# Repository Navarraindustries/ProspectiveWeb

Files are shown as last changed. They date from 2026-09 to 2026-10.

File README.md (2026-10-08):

# PROSPECTIVE Web

> Computer-assisted planning for cerebral aneurysm surgery, in the browser.
> FastAPI backend (VTK · SimpleITK · pydicom) + React/TypeScript frontend with
> real-time 3D and MPR viewers — the web port of the PROSPECTIVE desktop app.

---

## Table of Contents

- [Overview](#overview)
- [Status](#status)
- [Tech Stack](#tech-stack)
- [Project Structure](#project-structure)
- [Prerequisites](#prerequisites)
- [Installation](#installation)
- [Running the App](#running-the-app)
- [Environment Variables](#environment-variables)
- [Data Model](#data-model)
- [Session Lifecycle](#session-lifecycle)
- [Undoing Work](#undoing-work)
- [Choosing a Clip](#choosing-a-clip)
- [Navigation & Unsaved Work](#navigation--unsaved-work)
- [API Reference](#api-reference)
- [Running Tests](#running-tests)
- [Development Scripts](#development-scripts)
- [Relationship to the Desktop App](#relationship-to-the-desktop-app)
- [Known Limitations](#known-limitations)
- [Privacy & Security Notes](#privacy--security-notes)
- [License](#license)

---

## Overview

PROSPECTIVE Web is a clinical decision-support system for neurosurgical planning
of cerebral aneurysms. A clinician uploads a DICOM study and walks a seven-step
pipeline, with every step rendered live in 3D:

```
1 DICOM upload  →  2 Segmentation  →  3 Detection  →  4 Morphometry
      →  5 Treatment decision  →  6 Devices  →  7 Report
```

All medical image processing runs on the server (VTK + SimpleITK); the browser
renders meshes with vtk.js and 2D slices as server-rendered PNGs.

Every step of that pipeline is **reversible**: the mesh carries an undo/redo
history, the preprocessing can be rolled back to the original DICOM, and the
detection, morphometry, centreline, treatment decision and placed devices can each
be cleared without restarting the study. Nothing derived from a result outlives
the result itself, so the 3D scene, the measurements and the PDF can never
disagree with one another.

Beyond the pipeline the platform covers the surrounding clinical workflow:
patient registry, clinical cases, a durable archive of imaging studies with a
searchable preview gallery, resumable planning sessions, user signup with admin
approval, and a tamper-evident audit chain.

---

## Status

| | |
|---|---|
| Backend tests | **1594 passing** (`pytest`, 105 files) |
| Frontend tests | **459 passing** (`vitest`, 65 files) · `tsc -b` clean · production build clean |
| REST endpoints | **149** operations (28 routers), all authenticated except login/signup/logout; `/docs` and `/openapi.json` also require a session |
| Feature parity with desktop | **Complete** |

---

## Tech Stack

| Layer | Technology |
|---|---|
| API framework | FastAPI 0.110+ with Uvicorn |
| Medical imaging | SimpleITK 2.3, VTK 9.3, pydicom 2.4, scipy 1.12, Pillow 10 |
| Mesh processing | VTK (Marching Cubes, smoothing, decimation, STL export) |
| Auth | python-jose (JWT HS256), passlib + bcrypt 4.x |
| Database | SQLAlchemy 2.0 + SQLite (WAL mode) |
| Report generation | reportlab 4.x (PDF), pydicom (DICOM SR) |
| Study archive | pluggable local filesystem or AWS S3 (boto3, optional) |
| Frontend | React 19 + TypeScript 5.8 + Vite 7 |
| 3D / 2D viewers | @kitware/vtk.js 36 (meshes, MPR, oblique reslice and MIP rendered client-side from a chunked int16 copy of the volume) |
| Routing | react-router-dom 7 |
| Python | 3.11+ (developed on 3.13) · Node 20+ |

---

## Project Structure

```
ProspectiveWeb/
├── Makefile                # Dev shortcuts
├── start-all.bat           # Windows: launches backend + frontend in two windows
│
├── backend/
│   ├── main.py             # FastAPI app: lifespan, CORS, static mounts, guarded routers
│   ├── requirements.txt
│   ├── models/    (20)     # Pydantic request/response schemas
│   ├── routers/   (23)     # Route handlers, one file per domain
│   ├── services/  (40)     # Qt-free business logic, shared with the desktop app
│   ├── test_*.py  (39)     # pytest suites
│   ├── data/               # PUBLIC static mount — sessions, meshes, reports
│   ├── clip_library/       # PRIVATE: institutional clips + templates (gitignored)
│   ├── study_files/        # PRIVATE archive: DICOM of archived studies (gitignored)
│   ├── user_files/         # PRIVATE: signup photos and CVs (gitignored)
│   └── secrets/            # PRIVATE: JWT signing key (gitignored)
│
└── frontend/
    ├── src/
    │   ├── pages/          # Landing · Login · Signup · Patients · NuevoCaso
    │   │                   # Studies · Workspace · PendingRequests · UsersAdmin · AuditTrail
    │   ├── components/     # Design-system primitives + one panel per pipeline step
    │   ├── vtk/            # MeshView · VolumeView · MprView · ObliqueMprView · Viewer
    │   ├── store/          # planning · auth · nav · theme contexts
    │   ├── *.test.*  (8)   # vitest + Testing Library suites
    │   └── styles/tokens/  # Design tokens (light/dark via [data-theme])
    └── public/media/       # Intro / loading / landing videos
```

Key backend services (all ported from the desktop `prospective/processing`):

| Service | Purpose |
|---|---|
| `dicom_loader.py` | SimpleITK series loading, multi-series scan, Enhanced XA multiframe |
| `thresholds.py` | Auto HU/intensity band per modality (CT · MR · XA · DSA strategies) |
| `preprocess.py` | HU clipping, isotropic resampling, Gaussian smoothing, bone subtraction |
| `segmentation.py` | Marching Cubes → component filter → smoothing → decimation |
| `mesh_crop.py` | Box/sphere ROI clipping · plane cut (no centre to pick) · region eraser |
| `mesh_components.py` | Connected-piece analysis: keep only the vascular tree, or delete one piece by click. Refuses on CTA, where the largest piece is the whole head |
| `aneurysm_detector.py` | Curvature + shape-gate candidate detection |
| `aneurysm_consensus.py` | Three independent channels — curvature, local calibre, calibre vs the neighbouring vessel — merged into one shortlist |
| `morphometrics.py` | Neck / dome / AR / DNR / BF / UI / EI / NSI with reliability guards |
| `sac_isolation.py` | Semi-automatic watertight sac isolation from two clicks |
| `parent_artery.py` | Parent-vessel diameter → size ratio |
| `centerline.py` / `cross_section.py` | Medial-axis extraction · diameter profile · stenosis |
| `perforator_risk.py` | Vertex-valence anomaly → perforator candidates |
| `treatment.py` | Heuristic CLIP vs ENDOVASCULAR scoring, every weight carrying its provenance |
| `jsdb.py` | Japan Stroke Data Bank: fitted poor-outcome risk for EACH route. Ruptured only; describes, never votes |
| `clips.py` / `coils.py` / `devices.py` | Device catalogues, recommendations, real VTK collision |
| `clip_selection.py` | Criteria-based clip choice per case + manufacturing spec |
| `clip_fit.py` | Poses candidates on the measured neck and checks them against the mesh |
| `clip_library.py` | Global store of the institution's clips and manufacturing templates |
| `navarro.py` | The NAVARRO™ made-to-order family: jaw sizing, jaw-only resizing |
| `clip_animation.py` | Splits a clip into body + blades and derives its hinge, for rehearsal |
| `clip_manufacture.py` | The clip to have made: family, commercial fallback, or neither |
| `clip_dossier.py` | The two order PDFs — internal record and workshop copy |
| `clip_orders.py` | The order register and the workshop directory — global, persistent, frozen |
| `stent_deployment.py` | Centerline-guided braided stent along real vessel curvature |
| `phases.py` | PHASES 5-year rupture risk (Greving 2014) |
| `mesh_prep.py` | 3D-print preparation + printer-bed presets |
| `scene_render.py` | Offscreen VTK renders of the scene from named, fixed viewpoints |
| `report_generator.py` / `dicom_sr.py` / `mesh_exporter.py` | PDF · DICOM SR · STL |
| `audit.py` | SkullChain SHA-256 tamper-evident event chain |
| `storage.py` / `study_archive.py` | Durable study archive (local or S3) + previews |
| `mesh_backup.py` | Undo/redo stacks for the working mesh, with a labelled manifest |
| `device_state.py` | Which devices a session has placed; clearing one family |
| `sessions.py` | Session dirs, TTL purge, durable snapshot / rehydrate |

### Segmentación tubular

El método tubular (`services/vascular_mask.py` + `mask_to_surface` en `services/segmentation.py`) rellena el núcleo de la banda de umbral y mide su tubularidad con Frangi por lonchas. Siembra en los troncos (percentil 90, ≥ 50 mm³) y crece por histéresis solo lo conectado a ellos. Después recupera hasta 3 mm de pared y sacos, vetando lo que es lámina (hueso). La superficie sale de marching cubes sobre la máscara suavizada, con un vóxel vacío alrededor que tapa los vasos que salen por el borde del volumen. Cada segmentación informa de las aristas de borde, las piezas, las semillas y los mm³ recuperados y vetados. `backend/scripts/validate_case3.py` mide todo eso sobre Case 3 (384³, 0,32 mm, umbral 1470), y en este equipo (16 núcleos) da estas cifras. La decimación (45 %) usa `vtkDecimatePro` con la topología preservada: la cuadrática abría 25 aristas de borde en una malla que llegaba cerrada.

| Case 3 | Cifra |
|---|---|
| Aristas de borde | 0 (2 no-variedad, aceptadas) |
| Piezas | 6 (1 con «solo el árbol»); ninguna con aspecto de hueso |
| Semillas | 8 |
| Relación de aspecto mediana | 1,43 |
| Lesión conservada (M0 a ≤ 3 mm) | 96,6 % |
| Vértices | 107 176 |
| Tiempo máscara + superficie | 9,0 s (34,1 s con los dos pases de Frangi) |

La variable de entorno `PROSPECTIVE_MEM_BUDGET_MB` fija el presupuesto de memoria por encima del cual el método tubular se fuerza a media resolución y lo dice. Si no está definida, el presupuesto es el 70 % de la RAM disponible que detecta el sistema (`/proc/meminfo` en Linux, `GlobalMemoryStatusEx` en Windows), y 1400 MB si no puede leerla.

La detección busca la curvatura sobre una copia de 80 000 vértices cuando la malla es mayor, y calibre y cociente sobre una de 40 000. Las regiones de curvatura que tocan una cara de la caja de la malla (las tapas de los vasos cortados por el borde del volumen) van al final de la lista. En Case 3 la lesión confirmada sale 2.ª, con «solo el árbol» y con la malla completa, y la detección tarda unos 10 s. Eso es **a resolución nativa**. A media resolución (10 594 vértices, «solo el árbol») la misma lesión sale 5.ª, el último puesto de la lista, y solo por el cociente: el objetivo «lesión ≤ 3» no se cumple ahí.

#### Despliegue

- **Memoria y resolución.** Case 3 (56,6 M vóxeles) necesita unos 2,1 GiB para el método tubular a resolución nativa. En una instancia de 2 GB el presupuesto automático (70 % de la RAM disponible) no llega, así que los estudios de ese tamaño se segmentan siempre a media resolución: la tarjeta lo dice («1/2 · Submuestreada») y la lesión de Case 3 cae al 5.º puesto. Recomendado: una instancia de 4 GB, que pasa justo, o fijar `PROSPECTIVE_MEM_BUDGET_MB` a lo que la máquina aguante de verdad.
- **Tiempo.** A media resolución, máscara más superficie de Case 3 tardan unos 27 s en un solo núcleo del equipo de desarrollo, casi todo en los dos pases de Frangi. En una vCPU compartida hay que contar con 40–80 s.
- **Proxy inverso.** La interfaz lanza la segmentación con `POST /api/segment?background=true`, que responde 202 al instante, y recoge el resultado en `GET /api/segment/result/{sid}` (409 mientras sigue en curso), así que ninguna petición dura minutos y el límite típico de 30 s del proxy basta. Sin `background` el endpoint sigue siendo síncrono, para scripts. El progreso va por `/ws/progress/…`, así que el proxy también tiene que reenviar `/ws/` con las cabeceras de actualización:

  ```nginx
  location /ws/ {
      proxy_pass http://127.0.0.1:8000;
      proxy_http_version 1.1;
      proxy_set_header Upgrade $http_upgrade;
      proxy_set_header Connection "upgrade";
      proxy_read_timeout 180s;
  }
  ```

  Sin eso el panel cae al sondeo por GET cada medio segundo, que funciona igual pero con más peticiones.
- **Un solo proceso.** Arranca uvicorn con un único worker (sin `--workers N`). El progreso de cada trabajo y el semáforo que deja correr una sola segmentación tubular a la vez viven en la memoria del proceso: con varios workers, el progreso se consultaría en un proceso que no es el que segmenta, y dos segmentaciones tubulares podrían correr a la vez y agotar la memoria. Está defendido: al arrancar, cada proceso toma un cerrojo exclusivo del sistema sobre `backend/data/.proceso.lock`, y un segundo proceso sobre los mismos datos (otro worker, o un uvicorn antiguo que siguiera vivo) no arranca y dice por qué. `PROSPECTIVE_ALLOW_MULTI_PROCESS=1` lo desactiva; solo lo usan los tests.

---

## Prerequisites

- **Python 3.11+** and **Node.js 20+**
- Windows / macOS / Linux (VTK and SimpleITK are cross-platform)

---

## Installation

```bash
git clone https://github.com/JEsteban1999/ProspectiveWeb.git
cd ProspectiveWeb

# Backend
cd backend
python -m venv .venv
.venv\Scripts\pip install -r requirements.txt      # Windows
# .venv/bin/pip install -r requirements.txt        # macOS / Linux

# Frontend
cd ../frontend
npm install
```

Or, on Windows, with the Makefile from the repo root:

```bash
make install:backend
make install:frontend
```

---

## Running the App

Double-click **`start-all.bat`** (Windows) to launch both servers, or run them
separately:

```bash
# Backend — http://127.0.0.1:8000
cd backend && .venv\Scripts\uvicorn main:app --reload --host 127.0.0.1 --port 8000

# Frontend — http://localhost:5173
cd frontend && npm run dev
```

| URL | Description |
|---|---|
| `http://localhost:5173/` | Public landing page |
| `http://localhost:5173/app` | The application (login → patients → workspace) |
| `http://127.0.0.1:8000/docs` | Swagger UI |
| `http://127.0.0.1:8000/redoc` | ReDoc |
| `http://127.0.0.1:8000/health` | Health check |

Default account seeded on first run: **`admin` / `admin123`**. Change it from the
user menu ("Cambiar contraseña") before using the app with real data — an admin
can also reset another user's password from the Usuarios page.

> **Note on `--reload`**: uvicorn's reloader does not reliably pick up *new*
> modules, and a stale process on :8000 will silently serve old code. Restart the
> backend for real when verifying a change end to end.

### With Docker

```bash
docker compose up --build -d      # → http://localhost:8080
```

Two containers: the API (`backend/Dockerfile`, one uvicorn process — progress
and background results live in memory) and nginx (`frontend/Dockerfile`) with
the built app, which also forwards `/api`, `/data` and `/ws`. Browser and API
share one origin, so the session cookie stays `SameSite` and no CORS is needed.
The database, the study archive, user files, the JWT key and the clip folders
live in named volumes; none of them is copied into the image
(`backend/.dockerignore`). `PROSPECTIVE_PORT` changes the port. Before real
patient data: put HTTPS in front and set `COOKIE_SECURE=1`. CI builds both
images and checks they answer.

---

## Environment Variables

The server runs out of the box with sensible defaults.

| Variable | Default | Description |
|---|---|---|
| `PROSPECTIVE_DB_URL` | `sqlite:///backend/data/prospective.db` | SQLAlchemy connection string |
| `JWT_SECRET` | auto-generated into `backend/secrets/jwt_secret.txt` | HS256 signing key |
| `SESSION_TTL_HOURS` | `24` | Age at which an idle working session is purged |
| `STUDY_FILES_ROOT` | `backend/study_files` | Root of the durable study archive |
| `STORAGE_BACKEND` | `local` | `local` (filesystem) or `s3` |
| `STORAGE_S3_BUCKET` | — | Required when `STORAGE_BACKEND=s3`; bucket must be private |
| `STORAGE_S3_PREFIX` | — | Optional key prefix inside the bucket |
| `COOKIE_SECURE` | off | Mark the auth cookie `Secure` (set it when serving over HTTPS) |
| `PROSPECTIVE_ALLOW_DEFAULT_ADMIN_PASSWORD` | off | `1` skips the forced change of `admin123` (tests, local dev only) |
| `CORS_ORIGINS` | Vite dev server | Comma-separated origins allowed to call the API with credentials. `*` is refused |
| `PROSPECTIVE_PLAN_VIEWS` | probed | `0` / `1` forces the report's server-rendered plan views off / on. Unset, a child process probes once whether offscreen OpenGL works: on a machine without it VTK does not raise, it kills the process |
| `BACKEND_URL` | `http://127.0.0.1:8000` | Where the Vite dev server proxies `/api`, `/data`, `/static` |

Token lifetime is currently a constant (`ACCESS_TOKEN_EXPIRE_MIN`, 24 h) in
`services/auth_service.py`, not an environment variable.

For production, always set `JWT_SECRET` from the deployment environment and never
commit it.

---

## Data Model

The clinical hierarchy is deliberately four levels deep, so one episode of care
can carry several acquisitions without duplicating records:

```
Patient  ──<  Study (clinical case)  ──<  ImagingStudy (one acquisition)
                      │                            │
                      └──────<  PlanningSession  >─┘
```

- **Patient** — demographics, history, institution.
- **Study** — the *clinical case*: diagnosis, aneurysm type, region, laterality,
  proposed treatment. Created via "Nuevo caso" against an existing patient.
- **ImagingStudy** — one archived acquisition (CT, angiography, follow-up) with
  its DICOM in durable storage plus a rendered preview. A case may hold several.
- **PlanningSession** — a saved run of the pipeline, linked to both the case and
  the acquisition it analysed, resumable from the step it was saved at.

The **Studies gallery** (the "Estudios" tab, and inside each patient sheet) lists
archived imaging studies as preview cards. The search runs **on the server**, so
it covers the whole archive — filtering only the page that happened to be loaded
made an older patient come back empty with nothing to explain why.

Each card shows the step its planning reached and offers two actions:
**«Reanudar»** restores the saved session at that step, and **«De cero»** starts a
fresh session at step 1 and says so. A card only offers to resume when the
snapshot is really on disk: sessions saved before durable saving existed, or
purged since, would otherwise fail on restore.

---

## Session Lifecycle

Every pipeline interaction is scoped to a **session** — a UUID directory:

```
backend/data/sessions/{uuid}/
├── .created_at          # ISO timestamp used for TTL cleanup
├── state.txt            # Key-value store (dicom.*, seg.*, morpho.*, treatment.*)
├── dicom/               # Uploaded DICOM files
├── meshes/              # Meshes (.vtp) + cached volume (_volume.npy)
│   ├── _undo/           # Mesh edit history + index.json manifest
│   └── _redo/           # States stepped back past, replayable
├── reports/             # Generated PDFs
└── exports/             # Exported STL files
```

Sessions are working scratch and are purged after `SESSION_TTL_HOURS`. Two
mechanisms make work survive that sweep:

- **Archiving a study** copies its DICOM into `study_files/` (or S3) and creates
  an `ImagingStudy`. This is what puts it in the gallery.
- **Saving progress** snapshots the session directory into
  `data/session_saves/{uuid}`. The DICOM is hard-linked rather than copied
  (studies are ~1 GB and copying them filled the disk); meshes and the volume
  cache are copied, because re-running a step rewrites them in place and a
  snapshot must stay a point-in-time image. The mesh undo/redo stacks are pruned
  out of the snapshot — they are a working convenience, and carrying every
  intermediate state multiplied the size of each save.

A restored session starts its own clock. `_clone_tree` copies every file in the
snapshot, `.created_at` included, so a session restored from a week-old save came
back already past the TTL and the next purge sweep deleted it mid-session, with
no message — any session older than `SESSION_TTL_HOURS` was effectively
unresumable. The live session is stamped with the time it was actually created.

What survives a save → restore, verified end to end: the segmentation and every
mesh edit, the detection, the morphometry *including the fitted neck plane and
the points marked around the rim*, the centreline, the treatment decision, the
placed devices (and so the report), and any made-to-order clip built for the
case. The marks matter as much as the measurement: the plane can be rebuilt from
its origin and normal, but a resumed session used to show that plane with
nothing behind it, and refining it meant marking the rim again from scratch.

Typical flow:

```
POST /api/upload                       → session_id + detected series
GET  /api/segment/suggested-band/{id}  → auto HU band for this modality
POST /api/segment                      → vessel_tree.vtp
POST /api/detect/{id}                  → aneurysm candidates
GET  /api/morphometry/{id}             → neck/dome measurements
POST /api/treatment-decision           → CLIP vs ENDO recommendation
POST /api/report                       → PDF assembled from session state
POST /api/studies/cases/{case}/archive → DICOM into durable storage
POST /api/sessions/save                → resumable snapshot + DB link
```

Session files are served statically under `/data/sessions/` so vtk.js can fetch
mesh URLs directly — behind a middleware that requires the same token as the API,
since those directories also hold the uploaded DICOM.

---

## Undoing Work

A planning session is exploratory: thresholds get retuned, a crop takes a vessel
with it, a case is evaluated with the wrong location. Every step therefore
has a way back that does not cost a re-upload or a re-segmentation.

| What | How to undo it | Cost |
|---|---|---|
| ROI crop · region eraser · re-segmentation | «Deshacer» — `POST /api/mesh-restore/{sid}` `scope=undo` | file copy |
| Every interactive mesh edit at once | «Restaurar malla original» — `scope=original` | file copy |
| An undo taken one step too far | «Rehacer» — `scope=redo` | file copy |
| HU clipping · resampling · smoothing · bone subtraction | «Revertir» — `DELETE /api/preprocess/{sid}` | rebuild from the session's DICOM |
| Candidates + morphometry + the neck plane | «Limpiar detección» — `DELETE /api/detect/{sid}` | instant |
| Neck or dome marker placed on the wrong spot | Clear that one marker in the morphometry panel | instant |
| The medial axis and any stent deployed along it | `DELETE /api/centerline/{sid}` | instant |
| The recommendation, its clinical context and PHASES | `DELETE /api/treatment-decision/{sid}` | instant |
| A placed clip, coil packing or stent | `DELETE /api/devices/{sid}?kind=…` | instant |
| A wrongly imported custom clip | `DELETE /api/clips/custom/{sid}/{index}` | instant |

Two rules keep the session honest while all of this happens:

- **Nothing derived outlives its source.** Restoring a mesh clears the candidates,
  morphometry and centreline measured on the old one; clearing the detection also
  clears the treatment recommendation and the PHASES score, because both are
  computed *from* the morphometry. Leaving them behind produced a PDF that
  recommended a treatment for an aneurysm the same PDF reported as unmeasured.
- **Generated outputs are cache-busted and dated.** A PDF, a DICOM SR and an STL
  are snapshots of the mesh, the measurements and the devices at the moment they
  were written. The filename is fixed per session, so the URLs carry a version
  token and the panel says when a download no longer matches what is on screen.

The mesh history lives inside the session directory, so a session that is saved
and resumed still offers «Deshacer» — the browser has no memory of edits it did
not make, and `GET /api/mesh-restore/{sid}` is what the panel asks on mount. The
same applies to the preprocessing (`GET /api/preprocess/{sid}`), the placed
devices (`GET /api/devices/{sid}`) and the imported clips
(`GET /api/clips/custom/{sid}`).

---

## Choosing a Clip

The devices step answers a specific question: **does anything we own fit this
aneurysm, and if not, what has to be made?**

### Two stages

1. **Analytic** — every clip in the catalogue is judged against the case,
   criterion by criterion. Each verdict carries the measurement that produced it,
   because "score 92.6" is not something a surgeon can check.

   | Criterion | What it compares |
   |---|---|
   | Cobertura | Blade length against the **flattened** neck (see below) |
   | Fenestración | Window calibre against the measured parent artery |
   | Alcance | Shape against dome depth (AR) |
   | Forma / localización | Shape against the anatomical region on the case |
   | Fuerza de cierre | Spring force against neck width |

2. **Geometric** — the best candidates are built at their real dimensions,
   posed on the measured neck plane and checked against the patient's own mesh.

   Two details make this mean anything. A clip across the neck necessarily
   intersects the vessel — *the neck is vessel* — so the sac and neck region are
   cut away first and the collision test runs against what remains; a hit then
   means the blade reaches a **neighbouring** structure. And several approach
   angles are tried: reporting only the best pose made a clip that clears its
   neighbours at every angle look identical to one that clears them at exactly
   one. Both numbers are reported (`clean_rolls` of `n_rolls`).

### Four outcomes, never an empty list

| Outcome | Meaning |
|---|---|
| `stock` | At least one clip meets every criterion |
| `marginal` | Usable clips exist, but all carry a caveat — the custom alternative is offered too |
| `manufacture` | Nothing fits; the answer is a specification to have one made |
| `unmeasured` | No reliable neck, so no selection is possible — mark the neck plane first |

The old recommender returned an empty list for a 1 mm neck and for a 20 mm neck
alike. An empty list *is* the answer "nothing made fits this patient"; it just
has to be delivered as a specification rather than as silence.

### The manufacturing specification

Blade length, width, height, spring, shape, angle, target closing force, and the
window diameter taken from the measured parent artery. Width, height and spring
follow the median proportions of the real catalogue rather than being invented —
but never below the smallest part that demonstrably exists. Scaling every
dimension with the blade treats a clip as one shape at different zooms, and a
2.5 mm neck then specified a 2.8 mm spring, 44 % under the shortest real one.
The spread of spring/blade across the catalogue (0.45–1.14) already says the
relation is not proportional, and the NAVARRO™ family settles it: 42 designs from
7 to 22 mm of jaw, all on the same 14.3 mm body. A spring is sized by the force
it holds, not by the blade in front of it. When a dimension is floored the spec
says so. `POST /api/clips/manufacture/{sid}` writes the STL.

**The STL comes from the drawn designs.** It used to come from the box builder —
348 triangles with 696 boundary edges for a 10 mm clip, an open surface that no
workshop or printer can take. Anything meant to be MADE is now built from the
NAVARRO™ family, which is watertight.

**A shape the family cannot build is never substituted in silence.** Available
shapes are read off the disk, so the curved and fenestrated series become
selectable by dropping their files in. Until then a fenestrated case is offered a
commercial clip of that shape — and if no commercial clip of that shape can close
the neck either, the answer is `unavailable` rather than a near-miss presented as
an alternative.

**Two dossiers.** The internal PDF records which patient, which case and which
measurements produced the dimensions, so the order can be re-derived a year
later. The workshop PDF carries no patient data by construction — dimensions,
tolerances, material and the checks to run on the finished part. They share a
part number, which is the only thread between them.

**Both dossiers show the piece.** Three renders of the very solid that goes
into the STL — superior, anterior and oblique — so a workshop can see the shape
it is quoting. A dimension table catches an order that is dimensionally wrong; a
picture catches one that is dimensionally right and shaped wrong. They carry no
patient data: they are pictures of a clip.

**The closing force is a target, never a result.** It comes from the spring, the
alloy and the heat treatment; an STL has no material. Both dossiers demand it be
measured on the finished part before anyone calls the order done.

The spec always lists what a machinist still has to confirm — a specification
that hides its assumptions is worse than one that states them. In particular,
**no parent-artery measurement means no window diameter**: the spec says so
instead of quietly falling back to a plain clip.

### The NAVARRO™ family (made to order)

`NAVARRO™ - Variantes/` holds the institution's own designs — **66 of them,
across all four series**:

| Serie | Diseños | Se varía |
|---|---|---|
| **T1 recta** | 6 (7–22 mm de mordaza) | mordaza |
| **T2 curva** | 6 | mordaza, **solo tallas dibujadas** |
| **T3 angulada** | 36 (6 acodados × 6 mordazas) | mordaza y acodado |
| **T4 fenestrada** | 18 (6 mordazas × 3 ventanas) | mordaza y ventana (3/5/7 mm) |

The curved and fenestrated series arrived by being dropped into the folder, with
no import step and no code change to read them — which was the point of reading
the library off disk. All 66 exports are watertight solids in millimetres, on the
same frame, verified before wiring them in.

**Only this family is offered.** Clips from Sugita, Aesculap, Yasargil and Codman
are no longer proposed to a surgeon: the family now covers every shape the
selector can ask for, and a clip nobody here can obtain was a dead end — it could
not be personalised and it dragged the wrong piece into the manufacturing
dossier. That table is not deleted, because it is also the dimensional reference
the manufacturing spec derives its proportions and its floors from. Reference,
never an offer (`OFFER_COMMERCIAL_CLIPS`).

Three things about them are easy to get wrong, and each is enforced in code:

- **Use the STL, never the OBJ.** The `.obj` exports are in CENTIMETRES (measured
  ratio 9.996–10.008 against the STL across all 41 pairs) *and* unwelded — the
  7 mm clip reads as 14 334 loose triangles with 43 002 boundary edges, a
  triangle soup that cannot be collision-tested. The `.stl` are already in
  millimetres and watertight. Nothing is rescaled.
- **The name states the JAW, not the clip.** A "7mm" NAVARRO grips 7 mm on a part
  21.30 mm long (`total = jaw + 14.30 mm`, constant across the family). Measuring
  the envelope and recording it as the blade makes the selector reject, as
  "oversized ×5.3", the very clip that fits a 4 mm neck. `add_clip` therefore
  accepts a declared `blade_length_mm` that overrides the measurement.
- **The closing force is a band, not a figure.** 120–200 g by design, not yet
  characterised. It travels as a band and the force criterion is capped at
  `warn` for these clips however well the band sits — "meets the criterion" is a
  claim nobody can make yet.

**Visibility.** Stock and made-to-order answer different questions — what can be
picked up today, and what would be made for this case — so the recommendation
always shows at least the best of each. Ranking alone hid the family: a design
whose closing force is still a band is capped at `warn` on that criterion, and
with a 6 mm neck 28 of the 42 designs were viable while the best ranked 12th of
60, so every visible slot went to stock. The scores are untouched; only
visibility changed.

**Resizing.** These are manufactured per case, so the jaw is not restricted to
the six drawn sizes: `POST /api/clips/navarro/{sid}` builds any jaw length, and
the panel both suggests the one the neck asks for and lets it be set by hand.
The stretch applies to the **jaw only, along its own axis** — the body and spring
are left exactly as drawn, because a uniform scale would resize the spring too
and its closing force would no longer be the family's. That is legitimate rather
than invented: sampling the jaw taper at ten stations and normalising by length,
the profiles agree to within ~0.05 mm across the drawn sizes, so the designs are
one shape stretched. Where the jaw *starts* is read off each mesh rather than
assumed — it is 2.50 mm at 0° and 90° but 3.95 mm at 15°, because the knee takes
up room. A stretched mesh is a faithful preview for display and collision
testing, **not** the manufacturing master.

### «Fabricación», a step of its own

Ordering a piece is not planning a case. Everything in **Dispositivos** answers
*what do I put in this patient, and where* — one sitting, all inside the session.
Ordering answers *how do I get the piece made*: it takes weeks, involves an
outside workshop, its register lives outside the session, and it stays alive
after the plan is closed, because the piece still has to arrive and be measured.

So it is step 7 of 8, between Dispositivos and Informe, and it is **optional** —
most cases are served by a catalogue clip and never go near it. The rail labels
it as such: a new step between two mandatory ones reads as mandatory unless
something says otherwise.

It took the manufacturing sheet (STL and dossiers) and the order workflow out of
the clips tab: **844 lines, more than a third of a step that held ~2,270.**

Two things that had to move with it. The step list was written out **four
times** — the workspace rail, the landing page, the patient sheet and the study
gallery — and sessions store the step they were saved at as an **integer**. With
four copies, inserting a step renumbers some views and not others; and every
session saved on «Informe» (index 6) would have resumed on «Fabricación». The
list now lives in `frontend/src/pipeline/steps.ts` alone, and a recorded
migration renumbers saved sessions once. Data migrations that are not idempotent
now register themselves in `applied_migrations` rather than relying on luck.

### The perforator detector was measuring the triangulation, not the vessel

Asked to explain what the feature does. Its docstring states the premise:
«Branching points have significantly higher vertex valence than straight vessel
segments». Measured on a marching-cubes isosurface with three real bifurcations,
that premise does not hold:

    valence:  median 6.00 · std 0.31 · range 4-8

On a manifold triangulation every vertex has ~6 triangles wherever it sits —
valence describes the mesh, not the shape. With the threshold it used (z ≥ 1.5)
the result was worse than chance:

    near a junction ..........  30.3 % of the surface
    of the FLAGGED vertices ..  20.9 %      → enrichment ×0.69

A flagged vertex was *less* likely than a random one to be at a branch. And the
`radius_mm` the API reported as «estimated vessel radius» was the constant 0.4,
identical for every candidate, because the valence algorithm computes no calibre.

**`services/branch_origins.py` measures calibre instead**, which is what a branch
actually is — a thin tube attached to a thick one:

1. Rasterise the interior (`vtkPolyDataToImageStencil`: 42 M voxels in 0.1 s,
   against minutes for `vtkSelectEnclosedPoints`).
2. Euclidean distance transform → distance to the wall.
3. From each vertex, march inward along its normal and keep the largest distance
   found: the radius of the tube that vertex belongs to. A max over a cubic
   window cannot do this — the window must be at least as wide as your own
   radius to see your own axis, and once it is that wide a branch vertex reaches
   the *trunk's* axis and stops looking thin. The march stops on leaving the
   vessel, so a neighbouring artery cannot lend its radius.
4. Connected thin regions are branches, accepted only if what they attach to is
   ≥1.6× thicker — which is what separates a branch from a vessel that tapers.

On the same synthetic tree: **3 of 3 junctions, at x = −6.01, 3.00, 7.97**
(truth −6, 3, 8), with the calibre and the parent calibre measured rather than
assumed.

### Why real perforators cannot be seen, and what to do instead

Asked directly: why can the app not see real perforators — is something missing?
Nothing in the software. Measured across the 2 725 DICOM files in the project,
the typical CT voxel is **0.963 × 0.963 × 0.800 mm** and the best is
**0.500 × 0.500 × 0.670**. A perforator is 0.1–0.5 mm.

With a lumen around 350 HU against parenchyma at 40, partial volume settles it:

| vessel | voxel | fills | reads as | passes a 150 HU threshold? |
|---|---|---:|---:|---|
| **0.3 mm** | 0.96 × 0.96 × 0.80 | 8 % | **64 HU** | **no** |
| **0.3 mm** | 0.50 × 0.50 × 0.67 | 28 % | **128 HU** | **no** |
| 1.0 mm | 0.96 × 0.96 × 0.80 | 85 % | 303 HU | yes |
| 0.3 mm | 0.23 iso (XA) | 100 % | 350 HU | yes |

A 0.3 mm perforator lifts its voxel 24 HU above parenchyma in the common series.
No threshold separates that from noise, and no algorithm reconstructs data that
is not in the voxel — super-resolution would be guessing, which is worse than
silence. Only the rotational-angiography series in the corpus (0.23 mm isotropic)
could resolve one, and that is an invasive study, not routine planning.

What a surgeon uses instead is the microscope, and knowing **where they arise**.
`services/perforator_anatomy.py` is the second of those: a table from location to
expected perforator territory, with what it supplies, what an infarct looks like,
the surgical note, and a source for every entry that claims a risk — there is a
test that fails if one does not have one.

It is stated for what it is: anatomy of that location, **not a measurement of
this patient**, with variants common. And the entry for the cavernous carotid
says the territory does not apply there, because a silence at the basilar apex
and a silence in the cavernous segment mean different things.

It surfaces in the decision step beside the recommendation, and in the report
inside the branch section — where it completes a short or empty list. A basilar
apex report that said only «ninguna rama visible» would be withholding the one
thing that matters at that location: thalamoperforators arise there, within
0.4–4.7 mm of the apex and sometimes **from the apex itself**, and injuring them
means thalamic infarct, coma or death.

### The warning now reaches the decisions it should inform

The scan was computed from the beginning and died in a collapsible card under
Morfometría. `perforator` appeared nowhere in `report_generator`, `dicom_sr`,
`clip_selection` or `clip_fit` — so the branches near the neck never entered the
choice of clip, and never reached the PDF.

**In the device step**, `POST /clips/plan` now returns the branch origins the
placed clip actually reaches, nearest first, with their measured calibre. The
distance is to the **clip's geometry**, not to the neck centre, and that is the
whole point: the jaw length is what decides how far the closing line extends, so
measuring from the neck would answer identically for a 7 mm jaw and a 22 mm one.

Two implementation notes worth keeping. A point locator measures to the nearest
**vertex**, so on a coarsely tessellated blade a branch the clip crosses can sit
several millimetres from the closest corner and fall out of the warning; it uses
`vtkImplicitPolyDataDistance` against the surface. And the check never sinks a
plan — a failure logs and returns nothing.

**In the report**, a «Ramas visibles cerca del cuello» table with distance,
calibre and parent calibre. It prints **even when the list is empty**, and that
is deliberate: without the calibre floor beside it, «none found» reads as «none
there», and those are different claims.

### The feature is now called what it is

«Perforantes» promised something the imaging cannot give, in both directions: no
row was necessarily a perforator, and an empty list was being read as «there are
none» when it means «none are visible».

It reads **«Ramas cerca del cuello»** now — in the panel, in the workflow rail,
in the viewer legend and on the landing page — and says the rest out loud:

- each row carries its **measured calibre** (`⌀1.1`), where every row used to
  show the same 0.4 mm constant under an API field that called it «estimated
  vessel radius»;
- with results, a line stating that these are not perforators and why: below the
  scan's calibre floor the image does not resolve a vessel, and a perforator is
  0.1–0.5 mm;
- with no results, the same floor turns «none found» into «none visible above
  N mm», which is the only claim the scan can support.

The endpoint description says the same, so the OpenAPI page cannot promise
perforators either.

### Why the scan runs at segmentation and not later

The question that prompted this: after cropping the mesh to a box or a sphere,
where are the branches in the full tree?

Cropping **overwrites `vessel_tree.vtp`** — the endpoint's own description says
«re-run segmentation to restore» — and the analysis reads that file. Measured on
the test tree cropped to ±5 mm: the junction at x = −6 is simply gone, and the
open rim left by the cut reads as thin-attached-to-thick, **inventing an origin
at x = −4.3 where no junction exists**.

So the scan runs on the full tree the moment segmentation finishes, and its world
coordinates are frozen into the session. They keep landing where they belong over
the cropped mesh, because it is the same coordinate frame. The detector also
ignores open boundary rims now, so a cut can no longer manufacture a branch.

**What it still is not.** A true perforator is 0.1–0.5 mm and CT or MR
angiography does not resolve it, so it never reaches the mesh. This finds
*visible branch origins*. The result carries `calibre_floor_mm` — the diameter
the voxel size cannot resolve — so an empty list cannot be read as «there are
none».

### The verdict was breaking one letter per line

Reported from the application with a screenshot. «Recomendación: TRATAMIENTO
ENDOVASCULAR» rendered as `TRAT / AMIE / NTO / ENDO / VASC / ULAR` in the 265 px
side panel.

The heading shared a flex row with badges that do not shrink, and it carried
`overflow-wrap: anywhere`. Adding the coverage badge left the text roughly sixty
pixels, and `anywhere` does exactly what it says: it breaks mid-word rather than
overflow. The heading now owns its line and the badges wrap on their own row
below, with normal word wrapping — no rule that can shatter a word.

**And the provenance was shouting.** Every factor carried its full source
underneath, so seven factors meant seven paragraphs burying the thing being read.
The sources are now one line each — the long reasoning lives in the PDF and in
this file, where there is room — and they sit behind a «Ver procedencia» toggle,
folded by default. Still there, no longer in the way. The endovascular profile's
copy was trimmed on the same grounds.

### A recommendation outliving the measurements it came from

`_clear_detection_state` had guarded this since it was written, with the reason
next to it: «leaving them behind made the PDF recommend a treatment for an
aneurysm the same PDF reported as unmeasured». It guarded the re-detect path.
Two routes by which the same numbers change in ordinary use were not guarded.

**Re-measuring the neck by hand.** The automatic morphometry of an open detector
cap reports a neck of 0. The clinician evaluates the treatment anyway — the neck
factor is skipped — then marks the neck plane and the neck becomes 3 mm.
Measured, before the fix:

    2) decisión: CLIPPING QUIRÚRGICO · cobertura 59 %   ← computed with neck 0.0
    3) neck re-measured by hand: 2.99 mm (manual)
    4) stored decision: CLIPPING QUIRÚRGICO             ← the old one, untouched

The report would print a hand-marked 2.99 mm neck beside a recommendation
computed when that neck did not exist.

**Recomputing PHASES.** Since the small-aneurysm branch started consulting the
risk band, correcting the hypertension flag or a previous SAH changes what the
engine would have answered, and nothing told the stored decision.

Both now invalidate — and **only when the number actually changes**. That
condition is not caution, it is required: resuming a session re-runs the
morphometry to replay the hand-marked plane, so clearing on every read would make
the decision vanish by opening the step.

The frontend keeps its own copy, so it had the same hole on both routes.
`DetectPanel` and `MeshEditTools` already cleared it; `MorphometryPanel` and
`PhasesCalculator` were the two that had been missed.

**Still open, and deliberately not fixed here:** placed clips survive a neck
re-measurement. Their coordinates are what the surgeon chose, so a clip is not
wrong — but it was placed on the neck *as it was measured then*, and after
re-marking it may no longer sit on it. Silently deleting someone's placed devices
because they refined a rim is the wrong fix; the right one is a warning, and that
needs a design decision rather than a patch.

### The shape indices stopped voting and started describing

Three of the eight factors — aspect ratio, bottleneck factor, undulation index —
came from rupture-risk literature (Dhar 2008, Raghavan 2005). Neither paper
studies the choice between clipping and coiling, and neither validated
modality-selection model uses a shape index. They were 42 of the available
points.

Looking for where morphology *does* have backing turned up something sharper than
«unvalidated». The engine gave **+20 to endovascular for AR > 2**, reasoning
«geometry favourable for coiling». The most direct evidence about aspect ratio and
coiling says the opposite about durability: **AR ≥ 1.6 is associated with
recanalisation, OR 4.15 (95 % CI 1.57–11.00)**, in 307 unruptured aneurysms with
79 months' mean follow-up (Neurol Med Chir 2022).

Both claims are true and they are about different moments. A deep dome on a narrow
neck holds coils well on the day and recanalises more afterwards. Collapsing that
into one vote lost exactly the distinction that matters, so now both are said.

**`services/endovascular.py`** describes the endovascular option instead of voting
on it, using the morphology that is published for that question:

| what it says | from |
|---|---|
| Coiling simple / asistido (balón o stent) | the wide-neck definition exists *because* it predicts the need for adjuncts, with a measured gradient: above 1.6 usually not needed, below 1.2 almost always (Brinjikji, AJNR 2009) |
| Valorar diversor de flujo | large and giant aneurysms, and it prints the complication figure rather than burying it — up to 25 % in giant ICA (2026 meta-analysis, 1 893 patients) |
| Durabilidad | the AR/recanalisation odds above, framed as «plan the follow-up», not as a contraindication |
| Domo irregular | stated as a caution and explicitly labelled a **rupture-risk** index with no validation for treatment outcome — reasonable is not the same as measured |

The profile is computed **even when clipping wins**: a multidisciplinary session
compares both options, and describing only the winner leaves half the conversation
out of the report.

The three indices are still shown on the panel and in the PDF, tagged «no puntúa»
with their reason — the same pattern as the closing force and the blade opening in
the clip selector. Deleting a measurement because it cannot vote hides it; showing
it with its provenance leaves it arguable.

A missing aspect ratio no longer costs confidence in the decision, because it no
longer decides anything; it costs detail in the profile, which the profile says
for itself.

### The detector was looking for the wrong thing

Measured on `case 3`, the only study this project has a clinical annotation for
— the doctors place its aneurysm on the **basilar trunk**. Against that, the
detector returned **five candidates and all five were wrong**: they sat on the
jagged sheet under the tree, where torn edges give high curvature. The real
lesion was in none of them.

It does not stand out by curvature. It is **the thickest point of the whole
tree** — 2.33 mm radius against a 0.57 mm median. No amount of tuning the
curvature gates was going to find it.

Two biases were fixed first, and both still hold:

- **The radius was measured on the patch, not the dome.** `sqrt(area / 4π)`
  treats the convex cap as a full sphere; a least-squares sphere fitted to the
  same points gives **1.75×** more (p10 1.53 · p90 2.35). So `min_radius_mm =
  1.5` was really demanding a ~5 mm aneurysm, and discarded **124 of 144
  regions**.
- **The positive-Gaussian fraction penalises whoever crops well.** A large
  region reaches the neck, and a neck is a saddle: negative curvature. Across
  case 3's regions the correlation between size and Gauss⁺ is **−0.29**, and
  the highest fraction (0.75) belongs to a twenty-point speck.

Then two geometric channels were added (`aneurysm_consensus.py`): **local
calibre**, and **calibre against the 6–14 mm ring around it** — the second is
what tells a sac from an artery that is simply wide, since a uniform tube
scores ~1.

**The ordering is by declared rules, not fitted weights**: best rank in any
channel, then how many channels agree, then the sum of ranks. With one
annotated point, any formula would be overfitting with a nicer name. Ordering
by *best rank* rather than by agreement is deliberate — case 3's lesion is
found by a single channel, and rewarding agreement would have buried it.

**What is not promised is the order.** Between two meshes of the same study
differing by 17 vertices out of 12 776, the top curvature candidate moved from
rank 1 to rank 4, with a deterministic pipeline. That is why the panel stopped
badging the first one as «Principal», and why `test_detector_case3.py` only
asserts presence.

### The blue patch is not the sac, and the sac already existed

For a geometric hit the highlighted mesh is a **ball around the point**, so it
includes vessel wall: it says *where to look*, not *what the lesion is*. It is
labelled `patch_kind: "locator"` rather than left to look like a segmentation.

Delimiting the body automatically was tried and does not work:

| stopping rule | extent |
|---|---|
| calibre > 1.25× the neighbouring vessel | 31.3 mm — leaks down the trunk |
| ratio > 1.3 / 1.6 / 2.0 | 19.2 / 16.6 / 11.0 mm — no natural cut |
| positive Gaussian, raw | 3.4 mm — drowns in mesh noise |
| positive Gaussian, smoothed | 11.5 mm, *stable* across 8/15/25 passes |

The last one looked convincing. Validated against synthetic sacs of known size
glued to a tube, it returned **27.5 mm for a 4, 6 and 8 mm sac alike** — it was
not finding the dome, it was flooding the tube. A cylinder has **zero** Gaussian
curvature, so "positive Gaussian" never stops at a vessel; and the stable
11.5 mm was the distance cap, not convergence.

What does delimit the sac is the neck. That was already implemented: marking it
re-isolates the sac **from the volume** into `aneurysm_sac.vtp` — which was
being written to disk and never displayed. It now reaches the viewer through
`sac_mesh_url` and replaces the locator once it exists.

### Bone is removed by connectivity, because brightness cannot

The mesh arrives with the tree plus a handful of large blocks — measured on
case 3: eleven pieces, the smallest **228 mm³**, sitting 37–92 mm away. The
size filter cuts below 5 mm³, so it never reached them. They are bone.

And no threshold separates them. Sampling the volume inside each piece:

    TREE   median 3049   p5–p95 [-318, 6896]
    BONE   median 1590   p5–p95 [  531, 2192]

**99 % of the bone falls inside the tree's own range.** The best possible global
threshold (2199) would keep 61 % of the tree and still leave 4.9 % of the bone —
raising it to kill bone kills the distal vessels, which is where "the mesh comes
out broken" came from.

What does separate them is that they do not touch. «Solo el árbol principal»
keeps the largest connected component: case 3 → 60.3 %, case 9 → 63.7 %, and in
both that component **is** the tree. It refuses on CTA, where contrast touches
bone and the largest piece is the whole head (795 000–1 220 000 mm³) — there the
ROI crop and the region eraser are the answer, and the refusal says so instead of
doing nothing.

### The band's ceiling decides whether the lesion is on the list at all

The XA band is `[p99, p99.9]`, and the mask is `>= lower AND <= upper`, so the
ceiling drops the brightest voxels — in a contrast 3DRA, the cores of the
fullest vessels. That is not a detail: it decides whether the aneurysm is
detected.

    case 3              with the ceiling: the lesion ranks 3
                        without it:       rank 9, off the five-candidate list
    the 3DRA 384³ exam  with the ceiling: it does not appear at all
                        without it:       rank 1, 2.11 mm from the annotation

Opposite answers, so the checkbox cannot have a default. And it cannot be
decided automatically either: the obvious rule — drop the ceiling when it is
cutting the tree — was measured and does not separate the two. What the ceiling
removes is almost entirely bridges between pieces in **both** cases (88 % in one,
89 % in the other); the tree gets more connected either way. What actually
decides is *what makes each lesion stand out*: case 3's is the thickest point of
its vessel, and without the ceiling every dense vessel fattens and it stops
standing out. That depends on where the lesion is, which is the one thing nobody
knows beforehand.

So the app stops asking. «¿Cuál uso? Probar con y sin techo» segments and
detects both ways and shows the two lists merged, marking which configuration
each site comes from — the sites that appear in only one are the ones a wrong
choice would lose. It costs two segmentations and two detections (115 s on the
real exam), it runs at the same resolution the segment button will use, and it
writes nothing: choosing is still a separate, explicit step.

### The validated model itself, instead of a copy of it

A literature review of the clip-vs-endovascular decision turned up a gap that was
about variables, not weights: the two published models that actually choose a
modality — the Japan Stroke Data Bank score and SHARP — are built on age, WFNS
grade, Fisher grade, prior stroke, size and location. This engine had six
morphological factors and none of the clinical ones, so age, WFNS and Fisher were
added to the balance with hand-picked weights.

That was a **copy of a fitted model, made by hand**. The 72 and 80 year cut-offs
were literally the Japan model's. So the copy was replaced with the original, in
`services/jsdb.py`: a logistic regression over **3 547 aneurysmal subarachnoid
haemorrhages** (2 666 clipped, 881 coiled, 1998–2013), points assigned from the
odds ratios, validated on an independent series of 269. Neurol Med Chir (Tokyo)
2021;61(2).

**It does not vote, and cannot.** Its variables were already in the engine, so
summing both would count them twice — the same defect as the neck and the DNR
below. The split is: the JSDB owns the clinical side of a *ruptured* case, the
engine owns the geometry (which the model has none of) and the clinical side of
an *unruptured* one, where the JSDB does not apply at all — its whole cohort is
haemorrhage, so it returns nothing rather than two flattering zeros.

| | clipping | endovascular |
|---|---|---|
| Age | ≥ 72 → 1 | ≥ 80 → 1 |
| Prior stroke | > 1 → 1 | ≥ 1 → 1 |
| WFNS | II–III 1 · IV 2 · V 3 | III 1 · IV 2 · V 3 |
| Fisher 4 | — | 1 |
| Size > 15 mm | 1 | — |
| Location | vertebrobasilar → 1 | MCA or ACA → 1 |
| **max** | **7** | **7** |

Two scores, not one, and that is the point. The engine returns a *difference*: a
balance of 0 means "tie" and never "both routes look bad". Two separate scores can
say it, and that is the signal that actually sends a case to a multidisciplinary
session. The panel and the PDF flag it when both pass 3 points — a threshold this
application chose and declares as its own, because the authors publish no bands
and no AUC, only that the poor-outcome rate correlates with the points (p < 0.001).

`prior_stroke` is new to the whole application. The nearest thing that existed was
PHASES' `earlier_sah`, which is narrower — a previous haemorrhage from *another*
aneurysm.

**What the split changed, measured.** Rupture still weighs 30 — it rests on AHA/ASA
2023 Class I LOE A, and the rule that a Class I recommendation must not sit below
any other single factor (the largest of the others is 25) still holds:

    ACM no roto                     saldo +20  →  CLIPPING QUIRÚRGICO
    ACM ROTO                        saldo −10  →  DISCUSIÓN MULTIDISCIPLINARIA
    ACM roto + WFNS 5               saldo −10  →  DISCUSIÓN MULTIDISCIPLINARIA
                                               JSDB: clipping 3 · endovascular 4
    ACM roto + WFNS 5 + Fisher 4    saldo −10  →  DISCUSIÓN MULTIDISCIPLINARIA
                                               JSDB: clipping 3 · endovascular 5
    Basilar ROTO                    saldo −55  →  TRATAMIENTO ENDOVASCULAR

The grades no longer move the balance — the three ruptured MCA rows are identical
there — and they move the fitted model instead. Fisher 4 shifts only the
endovascular arm, which is the asymmetry a single 10-point weight could not carry.

**And when the two disagree, the decision says so.** The engine decides on geometry
and guideline; the JSDB on this patient's clinical profile. Neither sees what the
other sees, so a disagreement is not a fault in either — but hiding it would be
one, and a single number hid it by construction. It now prints as a DISCREPANCIA
note.

### One measurement was being charged twice

The neck scored for its diameter (25) and again inside the DNR (15), which *is*
dome ÷ neck: a narrow neck made the first small and the second large, so a single
measurement collected **40 of the engine's points — more than rupture**. That is
what made geometry dominate every clinical input.

And they were never two criteria. Brinjikji defines a wide neck as "neck ≥ 4 mm
**or** DNR < 2" — two halves of one published definition. They are now evaluated
together and score once, worth 25:

| condition | direction | points |
|---|---|---|
| neither criterion met (neck < 4 mm and DNR ≥ 2) | endovascular | 25 |
| neck > 5 mm **or** DNR < 1.5 | clipping | 25 |
| meets it narrowly (neck 4–5 mm, or DNR 1.5–2) | — | 0 |

The borderline band used to push *toward* endovascular (+5 for a 4–5 mm neck, +8
for a DNR of 1.5–2), which is an odd direction for something just classified as
wide. Neutral says what is actually happening: the criterion does not separate the
routes there.

The DNR is still displayed, tagged «no puntúa», saying where it was counted.

### "Which route?" is not "should we treat?"

The under-3 mm branch was the only place anyone asked whether to treat at all. At
8 mm the engine jumped straight to picking a route, and a verdict reading
"TRATAMIENTO ENDOVASCULAR" is read as though treatment were settled when nobody
settled it.

Every unruptured case now carries a note saying the engine answered *which route*,
not *whether*, and giving the PHASES figure when one exists. **It deliberately does
not change the verdict**: ESO 2022 frames the decision as rupture risk against
procedural risk, and this application does not compute procedural risk. Inventing a
diameter threshold to recommend surveillance would repeat exactly what the 3 mm
shortcut already got wrong. What can be done is to stop leaving the question
unasked.

### «What if the fields are empty?» — nothing is mandatory, and three cannot be

WFNS grades a subarachnoid haemorrhage, Fisher grades the blood on a CT, and the
JSDB itself only exists for a ruptured aneurysm. For an incidental one none of
them exists, so none can be required, and the panel only asks when the case is
marked as ruptured.

Nothing else is required either — a missing input has always just skipped its
factor. What was wrong was the reporting. Confidence came from |balance|, and the
balance grows by *adding factors*, so it measured how much data existed rather
than how much was known:

| data available | before | now |
|---|---|---|
| everything | Alta | 100 % |
| neck + AR + location | **Alta** | 71 % · Moderada |
| neck only | **Moderada** | 49 % · **Baja** |

(WFNS and Fisher no longer appear in this figure at all. They belong to the JSDB,
which declares its own `known_pct`; counting them here would drop two different
coverage bars for one missing input.)

A verdict from one measurement was being presented as moderately reliable. The
result now carries `coverage_pct` — the share of the *available weight* the engine
could evaluate — and `missing_inputs`, naming what it did not see. Confidence is
capped by coverage, because agreement among the factors that were seen cannot make
up for the ones that were not.

One distinction the coverage keeps: a **neutral** factor is not a **missing** one.
An 8 mm diameter falls in the 5–12 mm band and scores nothing, but it was known —
the engine looked and decided it does not tilt. Only genuinely absent inputs cost
confidence.

### The rupture risk the app had already computed did not reach the decision

PHASES lives in the morphometry step and estimates a 5-year rupture risk. The
clip-vs-endovascular engine lives two steps later and takes its inputs from the
morphometry, none of which is PHASES. The only thing connecting them was a button
that clears both.

That was tolerable while they answered different questions — PHASES asks whether
to treat, the engine asks how — except the engine also answers the first one: an
aneurysm under 3 mm short-circuits to «VIGILANCIA ACTIVA», confidence **Alta**,
before evaluating a single factor. On diameter alone. So:

| same 2.8 mm aneurysm | PHASES | 5-year risk | engine said |
|---|---|---|---|
| Finnish, hypertensive, prior SAH, ACoA | 14 | **17.0 %** | vigilancia activa, confianza Alta |
| no risk factors, ICA, general population | 0 | **0.4 %** | vigilancia activa, confianza Alta |

Forty-two times the risk, same verdict, same stated confidence — two screens of
one application contradicting each other about one patient.

The shortcut now reads the stored score. A low or moderate risk still gets
surveillance and cites the figure; **a high one returns «discusión
multidisciplinaria»** and prints both numbers, because the two disagree and
saying so is more useful than picking one. With no PHASES computed the verdict
stands but confidence drops to Baja and the note says the recommendation rests on
diameter alone. A ruptured aneurysm never reaches the branch at all: PHASES is
validated on incidental aneurysms and says nothing about one that has bled.

No new threshold was invented for this. The bands are the ones `phases.py`
already applied, and where the app cannot resolve the comparison ESO 2022 frames
— rupture risk against procedural risk, and the procedural risk is not in this
application — it stops pretending the comparison is resolved.

### Every weight now says where it comes from

Two different things were being called evidence-based. The **thresholds** mostly
are published: a 4 mm neck and a dome-to-neck ratio of 2.0 are the standard
wide-neck definition (Brinjikji, AJNR 2009). The **weights** are not — no
published model assigns 25 points to a wide neck and 20 to an MCA location, and
nothing in this repository attributed them.

Every factor now carries a `source` naming both, and it travels to the panel and
into the PDF under the factor name. Three things it makes visible:

- the heuristic weights say `heurístico, sin fuente` rather than looking derived;
- the Aspect Ratio, Bottleneck Factor and Undulation Index say they come from
  **rupture-risk** literature (Dhar 2008, Raghavan 2005) and are not validated
  for choosing a modality — they are 42 of the available points;
- the rupture factor cites AHA/ASA 2023 Class I LOE A, and notes that its weight
  (15) is below the neck's (25) and the location's (25) despite resting on the
  strongest evidence of the eight.

Sitting in the same file is what a full literature review turned up and this
engine does not do: the two validated modality-selection models — the Japan
Stroke Data Bank score and SHARP — are built on age, WFNS grade, Fisher grade,
prior stroke, size and location. Six of these eight factors are morphological
instead. Age and comorbidities are collected here and deliberately not scored;
WFNS and Fisher are not collected at all.

### The bar was reading as a probability, so the bar is gone

«CLIP 72 % · ENDO 28 %» is the ratio of two heuristic sums normalised to 100. It
is not a probability, not a proportion of patients, and not a confidence
interval. The first attempt kept the bar proportional and put the raw points on
it instead of the percentage, with a line saying what they were.

That was not enough, and the clinical direction said so: **no score at all
leaves the engine now.** What goes out is the recommendation, its confidence,
how much of the case could be evaluated, and the factors with the side each one
pushes to and where its threshold comes from. What stays inside is the weighted
sum — the recommendation is still derived from it, and the invariants around it
are still tested — but it reaches no screen, no PDF and no session state.

    removed from the API   clip_points · endo_points · clip_pct · endo_pct · balance
    removed per factor     points  (the side it pushes to stays)
    removed from the PDF   the proportional bar and the «Pts» column
    removed from state     treatment.clip_pct and friends — still in the CLEAR
                           list, because sessions saved earlier have them

**The JSDB lost its counters too, and for a different reason.** It is a fitted
model, not a heuristic, so the instinct is to keep its numbers. But its authors
publish neither bands nor an AUC — they validate that the poor-outcome rate
correlates with the score, and nothing more. On screen «4 vs 2» reads as twice
the risk, which is exactly what the model does not say. What it does support is
the comparison, so the verdict («clipping is the less penalised route», «BOTH
routes look bad») and the variables penalising each route stay, without figures.

**PHASES is untouched**: it is a published instrument whose output is a rupture
probability, it lives in the morphometry section, and it is not what the
treatment engine adds up.

One thing had to be fixed to make any of this visible: the engine computed
`notes` and threw them away. `_to_dict` never emitted them, the model had no
field, and the report's notes loop had always printed an empty list. The whole
reasoning of the small-aneurysm branch — the part that now carries the PHASES
comparison — had never left the engine.

### Every placement collided, because the neck counted as an obstacle

Reported from the application: «I have tried several clips and there is always a
clip–vessel collision». There was. `POST /clips/plan` tested the clip against the
whole vessel mesh — sac and neck included — so it was asking «is the clip where it
should be?» and reporting «yes» as a collision. Closing on the neck is the
manoeuvre.

Measured on one geometry across the six rolls the verification uses:

| | whole tree | neck carved out |
|---|---|---|
| clean rolls | **0 of 6** | **4 of 6** |
| contacts at 0° | 1331 | 539 |
| contacts at 90° | 677 | 0 |

Every placement looked fouled, and the two rolls where the clip's body really did
sweep the parent vessel — 0° and 150° — were buried in the noise, which is the
part of the check worth having.

`clip_fit` had carved the neck since it was written; `test_clip_selection` even
says why, in a comment: «Without this every clip "collides", because the neck IS
vessel.» Only the placement path never learnt it, so the panel that judges a
candidate and the panel that places it disagreed about the same clip on the same
mesh. They now use the same obstacles, and there is a test that asserts they
agree roll by roll.

Two things came with it. `collision_detected` now means «touches anatomy outside
the neck», which is what a surgeon can act on, and the panel's label says which
question was answered rather than showing a bare Yes/No. And when no neck has
been measured the region cannot be carved: rather than report a number that
cannot separate the two cases, the result carries `neck_region_excluded: false`
and says the check needs morphometry to mean anything. The contact count is still
shown — what is withheld is the interpretation, not the data.

**The clips are not oversized.** A 7.5 mm jaw is the minimum a 5 mm neck takes
(see «The jaw is sized against the flattened neck»); the 18–25 mm behind it is the
spring and the grip, which the applier holds outside the field. That body can foul the vessel at a bad roll, and
now that the noise is gone, the check says so.

### The jaw is sized against the flattened neck, not against its diameter

A neck is not clipped at the width it has in the image. When the blades close,
the round section is squashed into a flat slit and what is conserved is the
**perimeter**, so a circular neck of diameter D closes along

    πD / 2  ≈  1.571 · D

That is the geometry behind the clinical rule. «Aneurysm clips: What every
resident should know» (Neurology India) puts it as: the neck diameter increases
by about 50 % when squeezed shut, so the blades should be 1.5 times the neck —
and the numerical study «Pre-selection blade size choice for the microsurgical
clipping of cerebral artery aneurysms» (2024) measures a deformation of at least
1.4×. Both are the same π/2 with more or less flattening. The same review says
what it is for: **incomplete closure at the distal side of the neck is the most
common cause of a dome that keeps filling.**

The selector used to aim at ×1.35 as the centre of a Gaussian, which had two
consequences: a blade that could not close the flattened neck merely scored
low instead of failing, and a blade *longer* than 1.35× scored worse than one
that fell short. Now the requirement is a **floor**:

- below it the clip fails outright — it does not close the neck;
- at it the clip is correct, because the deformation is already counted;
- above it, ranking prefers the shortest jaw that clears the requirement, and
  the ×3 cap plus the collision check still catch a blade whose tip lands on
  healthy tissue.

**The factor assumes a circular neck, and we can do better than assume.** When
the neck plane is marked, the contour is measured on the mesh and half its
perimeter is that patient's exact closing line. It matters because the stored
`neck_mm` is the *equivalent-circle* diameter derived from the contour AREA, and
for an oval neck that underestimates:

    neck 6.0 × 2.7 mm   →  equivalent circle 4.0 mm  →  rule says 6.0 mm of jaw
                           perimeter 14.2 mm          →  real closing line 7.1 mm

A measured perimeter is only trusted between ×1.5 and ×3 of the diameter: by the
isoperimetric inequality the circle is the *shortest* perimeter for a given area,
so reading less than πD means the plane caught two loops or an open contour, and
the rule takes over.

**What it broke, and that was worth breaking.** A 20 mm neck no longer has a
single-clip answer in the family — its closing line is 31 mm and the longest jaw
drawn is 22 — so it now returns a manufacturing specification instead of a piece
that would not close it. And the made-to-order offer used to be withheld whenever
a drawn size sat within half a step of the target; that had to learn the
asymmetry, because a drawn size *below* the requirement is not close enough, it
is short. A 5 mm neck wants 7.5 mm and the nearest drawn jaw is 7.

### The approach corridor stopped being two points and a line

Asked by the clinical direction: the software should assess the approach
trajectory, the viability of the procedure should depend on it, and it should
say what tissue is crossed and what could be compromised — or that nothing is.

What existed was a straight line. Entry and target were picked, depth and
incidence angle came back, a cylinder was drawn and that reached the report.
Nothing looked at what is *inside* the corridor, so it could not say whether the
approach is workable and it fed nothing downstream.

**What is measured now.** The corridor is a cylinder of radius `radius_mm`
(5 mm by default, and that is this software's assumption, published with the
result). Seventeen parallel rays are cast through its cross-section and
intersected with the patient's mesh:

| | |
|---|---|
| Vessels crossed | position, distance from entry, and calibre |
| Calibre source | the frozen branch scan when an origin is within 3 mm, else the longest chord a ray makes inside that piece, which approximates the diameter |
| Near misses | distance to the closest branch origin the corridor does *not* cross, with its calibre |
| Target exclusion | a ball around the aneurysm that grows with the sac — without it the dome itself counted as an obstacle and no approach was ever viable |

**The verdict is three states from explicit rules**, not a weighted sum — the
same reason the treatment engine stopped showing figures. A vessel of ⌀ ≥ 1.5 mm
in the way is `no_viable` («that does not move aside»); something thinner, or
passing within 2 mm of a branch origin, is `revisar` — it may be a vein or a
mobilisable branch, and that is the surgeon's call; anything else is `viable`.

**Two things it refuses to claim.**

*It does not measure bone.* Bone is not separable from contrast by intensity —
99 % of it falls inside the tree's own range, measured on case 3 — so the only
defensible statement is that there is **dense material where the vascular mesh
does not reach**. It is labelled that way, and it stays out of the verdict:
nothing here can tell the craniotomy from a deep bony obstacle. On a
**subtracted** study not even that: the image contains no bone and no
parenchyma, so the corridor can only speak about vessels, and it says so instead
of reporting «0 mm of bone», which would read as a clear path.

*Without a mesh there is no verdict.* The corridor comes back `null`, not
«viable». A verdict issued without having looked at anything is worse than no
verdict.

And the caveat that travels with every corridor: a 0.1–0.5 mm perforator never
reaches the mesh, so a clear corridor here is **not** a corridor without
perforators.

The verdict is persisted, printed in the PDF beside the depth and the angle, and
cleared with the trajectory — leaving it behind would describe a path nobody has
marked any more.

Still to come on this feature: having the software **propose** a corridor
(sweeping directions and keeping the clear ones), and letting it **feed the clip
recommendation**.

### Proposing a corridor: only vessels block, and never through the face

Second stage of the approach work. The software now sweeps 300 directions
around the aneurysm and returns the clear ones, best first.

**Only vascular tissue blocks.** That was the instruction, and it happens to be
the only thing the image separates reliably: bone shares its intensity range
with contrast. Nothing else vetoes a corridor.

**Two sectors are refused outright**, because an approach through them is not a
worse approach, it is one that does not exist:

    from below      more than 15° under the axial plane — the neck, the base
    the face        clearly anterior AND under 20° of elevation — orbit, nose

A frontal craniotomy is also anterior, which is why the face filter needs *both*
conditions: it comes in above the orbital rim and survives.

**Which way is the face?** That needs the patient's orientation, and it was in
the DICOM all along — just not where the loader looked. `ImageOrientationPatient`
sits at the root of a classic series, but in a multiframe 3DRA (what this project
has) it lives inside `PerFrameFunctionalGroupsSequence[i].PlaneOrientationSequence`.
Asking for the root attribute returned `None`, so nothing downstream knew where
anterior was. On case 3 the axes come out as: rows toward patient **left**,
columns toward **superior**, slices advancing **anteriorly** — so the mesh's +z is
the patient's front, which no one would have guessed. **Without those axes
nothing is proposed**: a corridor through the orbit could not be ruled out, and
proposing blind is worse than not proposing. A placeholder orientation (exact
identity plus a position at the origin, what a default exporter writes) is used
but flagged as unverified.

**What is proposed is a direction, not a craniotomy.** Naming an approach needs
the skull and the scalp, and a 3DRA reconstructs a cylinder around the vessels
that does not reach the scalp at all. So each proposal reads «posterior left,
28° above the axial plane», and says whether its entry point is real skin or
just the edge of what the study images.

**Two measurements that had to be fixed against real data**, both found by
running it on case 3 rather than on synthetic tubes:

- *The head threshold.* A 3DRA is not in Hounsfield units — case 3 ranges from
  −15 000 to 33 000 — so «air» cannot be a constant. Calibrating «inside» from
  the central block put the cut at −553, which is **above** the parenchyma
  (−400): the ray left the head 13 mm from the aneurysm and called it skin. An
  entry on the skin 13 mm from an intracranial lesion does not exist, and the
  software was reporting it confidently. The global median fails the other way
  (it collapses when the head is under half the field, normal in CT), and Otsu,
  tried, separates *contrast* from everything else — on case 3 it cuts at −33
  and leaves 82 % of the head outside. The p75 is tissue in both regimes.
- *Speed.* 100 s for 300 directions. The locator was rebuilt per direction, but
  that was only 10 % of it: the real cost was recomputing the head threshold —
  a percentile over 56 million voxels — once per direction. Hoisted, plus a
  cheap single-ray first pass before the 17-ray beam, it is **0.9 s**.

### The corridor picks the piece, and the rehearsal shows the corridor

Third stage. The direction asked that the approach drive the clip
recommendation, and that the placement video include the established
trajectory.

**The bend a corridor demands is geometry, not a table.** The blades have to sit
*across* the neck — lying in the neck plane — and the shaft comes out along the
corridor. The angle between those two directions **is** the bend the piece
needs:

    bend = 90° − angle(corridor, neck→dome axis)

A corridor lying in the neck plane (90°) is served by a **straight** clip,
because in a straight clip the shaft and the blades are the same line. One
coming down the dome axis (0°) would need 90° of bend for the blades to lie
across. The trajectory endpoint already returned that angle; it now reaches the
selector.

**This criterion votes**, unlike the blade opening and the closing force, which
are shown and do not. The difference is where the number comes from: how much
clearance a surgeon wants over the neck is a judgement nobody has signed, while
the angle between the corridor and the neck plane is fixed by the two
directions. A straight clip does not go down a corridor arriving at 60° to the
neck plane, and that is not an opinion. It degrades rather than disqualifies —
a few degrees can be recovered by opening the field, and a corridor is an
intention, not a rail. Without a marked trajectory the criterion **does not
exist**, rather than assuming the most convenient corridor for each clip.

Priority is unchanged where it should be: a wide neck still argues for a curved
piece, because blade curvature and shaft bend are different axes. The corridor
still reaches the ranking through the criterion.

**The rehearsal.** The animation already used the marked trajectory — but a
**resumed** session came back without it. The points were on disk and in the
PDF, the store was empty, so the viewer drew no corridor and the rehearsal
silently fell back to its default approach: the video showed a manoeuvre nobody
had planned. There is now a `GET /api/trajectory/{sid}`, and resuming restores
it. And the corridor is no longer drawn as a ruler line but as the **volume it
is** — a translucent 5 mm tube — because what the video has to show is the clip
and its applier coming down a space they have to fit through.

### «Can you simulate how the aneurysm deforms?» — half of it, honestly

The clinical direction asked for a simulation of the sac deforming as the jaw
constricts it. That can be programmed and it cannot be defended, so what got
built is the half that can.

**Why the deformation itself is out of reach.** A wall deformation needs the
wall's **thickness**, its **mechanical properties** and the **intraluminal
pressure**. None is measurable here: an aneurysm wall is 0.05–0.5 mm and this
project's voxel is 0.32 mm. And there is nothing to validate the result
against. It is the same dead end as the Alvarado-style score that was already
turned down — a convincing video comes out and nobody can say it is true.

**What is answerable is the clinical question behind it: how much aneurysm is
left.** When the blades close, what lies on the dome side leaves the
circulation and what lies on the artery side stays in. That is geometry over two
objects that already exist — the isolated sac and the placed clip — so
`GET /api/clips/occlusion/{sid}` splits the sac at the clip's closing level and
measures both sides:

| | |
|---|---|
| excluded | what the clip takes out of circulation |
| remnant | what stays connected to the parent artery — the number that matters |
| remnant width | across the neck plane |
| outcome | complete occlusion · neck remnant · residual aneurysm |

Both halves are capped before measuring, because an open surface has no volume
worth reporting; the test asserts that they add back up to the sac. With several
clips the most **proximal** closing line rules — anything above it is already
excluded by it — and for a picket-fence construct that is an approximation, said
out loud.

**The one deformation this project does assert** lives elsewhere and comes from
conserving the perimeter: the round neck is flattened, and its closing line
measures half the perimeter (see «The jaw is sized against the flattened neck»).
That is not a model, it is a length.

The result carries what it is not: geometry rather than mechanics, why the wall
cannot be deformed with this data, and that the 15 % cut between «neck remnant»
and «residual» is a presentation convention of this software rather than a
validated clinical threshold.

**And the illustration, asked for explicitly as one.** «Show the sac being
constricted, from geometry only, leaving the clip's physical and material
properties out for now.» So the rehearsal plays it: four frames of the sac
narrowing between the blades, from 25 % to 100 % of the closure, swapped in as
the closing phase advances.

It is a displacement field, and it says so. Points inside the grip are drawn
toward the blades' mid-plane; the influence fades with distance from the closing
line — a **compact** falloff, not a bell, because with a Gaussian the dome 6 mm
away still narrowed by 12 % and the drawing implied the clip squeezes what it
does not touch. Nothing outside the jaw length moves either, so a sac wider than
the blade is not crushed whole. **No wall yields, no volume is conserved** — real
tissue displaces somewhere and here it goes nowhere — **and no property of the
clip or its material takes part.** It is a drawing that moves.

What *is* true of the drawing is **where** it flattens and **in which
direction**: both are read off the placed clip's own geometry (the axis the
blades close along and the axis of their length, taken to the clip's pose),
not set as parameters. And the frames are computed in the backend rather than
in the viewer, because a deformation is a different geometry per moment — not
something a matrix can do on the GPU.

### Two clips, when no single blade closes the neck

Asked by the clinical direction: *can multi-clip treatments be supported, or is
this single-clip only?* Half of it already worked and half of it did not, and
the half that did not was the half that matters for a large neck.

**Placement was never single-clip.** `POST /api/clips/plan` takes a *list* of
placements, builds each clip at its pose, combines them, and measures neck
coverage and collisions **on the combination**; the panel lists the clips placed,
the report prints them all, and a catalogue clip and a custom one can sit in the
same plan. What was single-clip was the **recommendation**: for a neck no blade
closes, the only answer it had was «have a longer one made».

That left out what is actually done in theatre, and it is described technique:

- **tandem / stacked** — one clip parallel to the parent vessel, others stacked
  under or over it reinforcing the closure;
- **picket fence** — several clips in a row, **overlapping** and staggered along
  the neck, rebuilding it in sections. The published series does a giant MCA
  with seven fenestrated clips and an AComA with four.

So the selector now also computes a construct: the fewest jaws **that exist**
whose combined closing line covers the requirement. With `n` equal jaws of
length `j` overlapping by `s`,

    coverage = n·j − (n−1)·s

The overlap is the point. Blades are laid overlapping, not end to end: letting
them meet at the tips leaves the join unclosed, which is the same way of failing
that the flattened-neck rule exists to prevent. **The 2 mm is this software's
assumption** — the sources describe the overlap without giving a distance — so it
is named, shown on screen and listed as a question for the surgeons.

It is offered **beside** the manufacturing specification, never instead of it:
for a 20 mm neck (30 mm of closing line, longest drawn jaw 22 mm) the two real
answers are «have a 30 mm jaw made» and «put two 16 mm clips overlapping 2 mm»,
and choosing between them is the surgeon's call. Three things the construct says
about itself: which technique to use is not its decision, the overlap is an
assumption, and the accumulated weight of several clips can kink the parent
vessel — reported after tandem clipping (J Neurosurg 2015;123:472).

Capped at four clips. The picket-fence series reaches seven, but proposing a
long row from geometry alone is further than this software can see.

### The blades never opened as far as the mechanism does

Noticed from the application, watching the rehearsal: the jaw did not look wide
enough for the neck it was going onto. Two separate things behind that, and only
one of them was a bug.

**The angle was solved with a tangent.** `blade_swing_deg` set the swing so that
`lever · tan θ` equalled the half-gap. But a blade tip does not slide along a
line at the end of the lever — it rides an arc, so turning by θ carries it
`lever · sin θ` sideways, and sin θ < tan θ. Every clip in the rehearsal opened
short of its own applier: measured, 2.0 % on the 22 mm jaw up to 6.7 % on the
10 mm one, always in the same direction, never wide. Arcsine now, and the tips
part by exactly the specified opening on all six drawn sizes.

**And a whole dimension was going unjudged.** The jaw LENGTH has to span the
neck; the OPENING is perpendicular to it and is capped by the applier rather
than the blade — a 22 mm jaw parts no further than a 10 mm one. The criteria
were `coverage`, `reach` and `force`, none of which looks at that axis, so a
15 mm neck was handed a 19 mm jaw, correct on everything it was asked, whose
tips never part beyond 10 mm. Nothing said so.

There is an `opening` criterion now, and it **warns without voting** — weight
0.0, like the closing force, but for the opposite reason. The force is a
constant and cannot rank anything; the opening discriminates perfectly well, and
the problem is that how much clearance over a neck is enough is a clinical
judgement nobody here has signed. Weighting an unvalidated threshold would
reorder the list on an opinion. The arithmetic is not an opinion: the tips part
this much, the neck measures that much, and when the first does not exceed the
second it says so — along with whether the figure is the designer's or inferred
from commercial clips.

### The custom jaw was a picture, not a piece

`CustomJawOut` carried a preview mesh and an STL and no id. So a made-to-order
length could be dialled, looked at and downloaded — and not placed. It never went
through the collision check, never reached `placed_navarro_id`, and the order
form went back to the length derived from morphometry instead of the one that
had just been chosen. The same number typed twice in two screens, with nothing
holding them together: the shape of the bug the Sugita report was about.

The id was already expressible — `navarro:t1:0:8.5` parses and `mesh_for_id`
rebuilds that exact mesh, verified identical across straight, angled and
fenestrated — it simply was not being emitted. Now it is, the sheet offers
«Elegir esta medida» through the same `onPick` the candidate cards use, and the
length chosen on Dispositivos is the length Fabricación prefills.

One thing that had to move with it: the rehearsal read the jaw off the catalogue
index, which holds only the drawn sizes, and fell through to the lever arm for
anything else. For a custom 8.5 mm jaw that is 11.4 mm — past the 10 mm ceiling
— so the application would have shown a wider opening than the piece has and
labelled the figure specified when it is still inferred. It reads the jaw off
the id instead.

### The report did not know the device was still being made

Fabricación went in between Dispositivos and Informe, and the Informe was never
told. `report_generator` reads placed devices out of `device_state` and nothing
else, so the PDF printed «NAVARRO™ T4 Fenestrado ventana 5 mm, mordaza 8.5 mm»
and stopped — identically whether that piece was in the surgeon's hand or still a
drawing at a workshop three weeks out. A name says nothing about whether anyone
has made one.

The report now carries the order: number, piece, state, workshop, and what was
measured on the piece that came back. Three things it insists on.

**A piece outside specification is not a footnote.** Reception is the only place
the closing force stops being a design target, so a piece outside the band gets
its own sentence, in bold, saying not to implant it without the responsible
surgeon accepting the deviation in writing.

**The standing condition is stated on every made-to-order piece**, not only the
ones that go wrong: it is not a device with market approval, and its closing
force is a design target until it is measured.

**Nothing is said when there is nothing to say.** Most cases take a drawn size,
and a «no manufacturing order» heading on every report is noise that trains
people to skip the section on the reports where it matters. The one exception is
the case worth catching: a custom jaw placed with no order on file for the
session — a report describing a device that does not exist and that nobody has
asked anyone to make.

### The one shape the case can ask for and the family cannot draw

Filed as a housekeeping item — «BAYONET is still admitted in a couple of enums»
— and it was not housekeeping. `_preferred_shape` reads a region table, and the
paraclinoid carotid table rates BAYONET **first**, at 1.0. That is one of the
commonest locations there is, and the reason is real: a deep field under the
clinoid needs the shaft carried out of the line of sight.

The family draws four series and none of them is a bayonet, so
`navarro_shape_for` fell through its final `return STRAIGHT`. A paraclinoid case
was offered a custom jaw in the *straight* series — the worst of the four for
that field, because a straight clip is precisely the one whose shaft stays in the
way. Silently, with the reason text talking only about millimetres.

It now falls to ANGLED, which is what the family has that does the bayonet's job,
and the offer says it substituted:

> La familia no dibuja bayoneta: se ofrece angulada, que es lo que aparta el
> mango de la línea de visión en un campo profundo.

**What was already right and stayed untouched.** `resolve_perfect_clip` refuses a
bayonet outright — «Sin pieza ni sustituto: replantear el abordaje, o esperar a la
serie bayoneta» — and that is the correct answer for MANUFACTURE, as opposed to
for an offer. And `clip_library.VALID_SHAPES` keeps BAYONET on purpose: a hospital
can physically hold a bayonet clip, and the library records what is on the shelf,
not what this family makes. There is a test for each half, so the two do not get
levelled into one another later.

Two smaller things in the same pass: `services/__init__` still described `clips`
as a «Surgical clip library (42 models)», which stopped being what that module is
for; and `routers/clip_orders._shape_for_angle` was dead code that could only
ever return straight or angled — a sixth copy of the naming rule, waiting to be
called.

### The landing page was advertising the catalogue that was withdrawn

The one page a stranger reads before deciding whether any of this is worth their
time, and the last one anybody updated. It offered «42 modelos» from Aesculap,
Sugita and Codman months after those clips stopped being served — a catalogue the
application does not return and this institution cannot obtain — and promised a
«siete pasos» workflow directly above the eight step chips it draws from `STEPS`
itself.

Both are the same mistake: a hand-written claim sitting next to the data that
contradicts it. The step count is now spelled from the list. The clips card names
the family that is actually offered, with the four series and what is adjustable
about them. And «Fabricación» — a whole pipeline step, with an order, a workshop
and a dossier — was missing from the feature list and from what the page says you
receive; omitting the new is the other half of advertising the withdrawn.

`Landing.test.tsx` ties the copy to the data: the spelled number has to match
`STEPS.length`, every step label has to appear, and no withdrawn maker's name may
appear anywhere in the rendered page.

The animated walkthrough the page plays, `public/media/pipeline-hf.mp4`, was the
last copy of the seven-step claim: rendered in July, before the manufacturing
step existed, with «PASO 0N / 07» burnt into the pixels. Its source is a
HyperFrames composition in `frontend/hyperframes/pipeline-hf/`, so fixing it
meant editing the composition and re-rendering, not editing text.

Fabricación now has its own card between Dispositivos and Informe, labelled as
the optional step it is. The devices card was carrying the same withdrawn
catalogue the page did — «42 clips» were the Yasargil, Sugita, Aesculap and
Codman ones — and now reads «66 clips NAVARRO™ · 39 coils · stents».

Two things the extra 2.33 s forced. The video is 23.4 s → 25.7333 s (772 frames
at 30 fps), so the outro and the timeline loop moved with it. And the background
is one 12.200 s plate repeated, which no longer covered the running time in two
passes: there is a third now, and all three cuts were moved onto scene changes
— 11.5333 s is where Morfometría starts, 23.2 s the outro — so the jump in the
plate lands inside a cross-fade that was already there. Re-encoded at the same
1.55 Mbps the original used: like for like, 2.33 s longer.

Rendering it needs FFmpeg on PATH, which this machine did not have. Playwright
ships one built `--disable-everything` (VP8/WebM only — it cannot even decode the
h264 plate), and `imageio-ffmpeg` in the backend venv has a full build but no
`ffprobe`, which the renderer probes media with.

### A piece named by its bend alone

Five copies of one rule: how a piece of this family is named. `navarro`, the
order dossier, the order form, the orders register and the custom-jaw offer each
had their own. Three of them derived the name from the BEND — and a bend of zero
is the only thing a straight clip, a curved clip and a fenestrated clip have in
common.

So a curved order and a fenestrated order both read «recto» on screen, while the
delivery note the workshop received said «Curvo» or «Fenestrado ventana 5 mm».
The surgeon and the workshop were naming different pieces and believed they were
naming the same one. The custom-jaw offer did it to itself in a single object:
`shape` said `fenestrated` two fields above a `label` that said «T4 Recto».

The `shape` field was already there in every one of them. One function now, per
side: `navarro.shape_label` and its mirror in `components/planning/clipShape.ts`,
tested against the same pieces.

### Verification measured a different clip from the one being placed

Placement has always used the drawn mesh. `clip_fit.build_candidate_mesh` swept
boxes from the catalogue dimensions instead, so the collision test and the
coverage figure described a different object from the one that appears on the
neck — and the panel presents those numbers as a check on the clip you chose.

Worse, it read the bend off `shape`, the selector's COARSE class, which the
family outgrew when it started bending in 15° steps. Six drawn bends collapsed
onto two: 15° and 30° were verified as a 45°, 60° and 75° as a 90°. Four of the
six angled variants were checked against a bend they do not have, on the one
criterion — clearance around the parent artery — where the bend is the entire
point.

It now loads the drawn geometry by id, the same mesh placement uses, and falls
back to the approximation (with the real `bend_angle_deg`) only for a library
entry that has no mesh on disk. The end-to-end span of the six angled variants
now differs six ways and shrinks as the bend grows, which is the shape of the
truth: a clip that bends more reaches less far.

### The picker was still serving the catalogue that was withdrawn

Found by auditing what the recent changes left behind, not by a report. Dropping
the commercial clips turned off `OFFER_COMMERCIAL_CLIPS`, and `select_clips`,
`catalogue_with_library` and the placement index all honoured it. Two endpoints
did not: `GET /clips` and `GET /clips/recommendations/{sid}` still read
`CLIP_CATALOGUE` directly.

That is what fed the model picker on the devices step. So the panel above it
argued for a NAVARRO™ clip while the dropdown below offered eight from Yasargil,
Sugita, Aesculap and Codman — and preselected the first. Worse, the ids did not
match anything: the listing slugged clip NAMES while the placement index keys on
`identifier`, so every option was an orphan. `POST /clips/plan` does not reject
an unknown id — it logs and places a default 9 mm box. Choosing a clip and
getting a generic block, silently, is the same failure the Sugita report was
about, alive through a second door.

Three causes, three fixes. `spec_to_api` emits `identifier` instead of a slug of
the name. `catalogue_to_api` defaults to what is offered rather than to the
reference table. And the recommendations endpoint delegates to `select_clips`,
so there is **one ranker in the application** instead of two that could disagree
about which clips, in what order, under what ids.

One thing survived the merge deliberately: a session whose neck cannot be
measured — an open mesh — still gets a ranking against a typical 4 mm neck,
because answering with an empty picker blocked clip placement outright while the
coil catalogue stayed available. There is a regression test for that from the
first time it happened. What changed is that every line now says «orden general,
no específico de este caso». The version this replaces returned a generic
ordering that read exactly like a case-specific one.

### Resuming a session landed one step before where it was saved

`current_step` is stored as a NUMBER, and the resume path clamped it to `6` —
written by hand when the pipeline had seven steps. Inserting «Fabricación»
between Dispositivos and Informe made it eight, and the backend migrated saved
sessions from 6 to 7 on purpose, with a named migration. The clamp undid that
migration from the other side: a session saved on **Informe** reopened on
**Fabricación**, a step that user had never opened.

The number is gone. `clampStep` lives in `pipeline/steps.ts` next to the list
that defines it, which is the whole point of that module — its own docstring
warned that four hand-written copies of the step list would drift, and this was
the fifth copy, hiding as a magic number.

### A jaw made to size, in every series that can take one

The geometry always did this correctly — straight, angled and fenestrated all
come out the exact length asked for, measured on the mesh. The two paths that
EXPOSE it did not. `suggest_custom_jaw` derived only a BEND from the winning
candidate and never a shape, so a bifurcation case was offered a custom straight
jaw: the wrong piece at the right size, the same silent substitution the
commercial fallback used to make. And the endpoint that builds the preview had no
shape or window parameter at all, so a fenestrated custom jaw was unreachable.

Both now carry the shape and the window. The curved series still has no custom
size — its jaw is an arc — but that is a fact about the curved series, not an
answer to «can I have this exact length», which is yes in the three that stretch.
Returning nothing told the surgeon that, and hid the offer from most cases the
moment curved clips started winning ties.

### «Elegir» and «colocar» are two tabs

The clips tab held the reasoning, the rehearsal, the model picker, the placed
list with its coordinates, and the verification in one column past a thousand
pixels: moving a clip a millimetre meant scrolling past the whole recommendation
again. They are two tasks — which clip, and where it goes — and they now read
separately. The state is shared, so choosing in one places in the other, and the
sub-tabs sit at `size="sm"` because two bars at the same weight read as two
choices of equal rank.

### The recommendation, after the catalogue became one family

Measured across nine cases once the family was the whole catalogue: the top two
candidates scored **identically in eight of them**, the whole top five sat within
0–7 points, and a deep dome and a plain neck came back with the same five clips.
The selector was built to choose among 42 clips from four makers; pointed at 66
variants of one family — same body, same alloy, same uncharacterised force band —
it had stopped separating anything. Three causes:

**A criterion that is constant cannot rank, only dilute.** The closing force
scored 0.60 on all 66, and took a third of the weight doing it. It now carries
weight 0 while the band is provisional. It is not hidden — the caveat stays on
screen, and a band that could not hold the neck still fails the clip outright.

**The list did not answer the question being asked.** Six T3 angled 7 mm
differing only in bend, while the straight, curved and fenestrated never
appeared. «Straight, curved, angled or fenestrated» is the decision; «60° or 75°»
is a detail inside it. Each shape now contributes its best candidate, and no
shape takes more than two of the six slots. Scoring 90° above 60° above 45° also
went: what a bend buys is a shaft clear of the sac, which any bend gives, and how
much bend is best is not something the measurements answer.

**A warning that scored zero was indistinguishable from a failure.** The coverage
Gaussian bottoms out well before the ratio becomes disqualifying, so a 3 mm neck
came back with six clips at 0.00 points labelled usable. A `warn` means usable
with a caveat, so it keeps a floor; zero goes back to meaning what `fail` means.

Result: the top-five spread went from 0–7 points to 15, and the number of case
pairs returning near-identical lists fell from eight to three. **Ties at the top
are still common, and are now said out loud** rather than resolved by an
arbitrary tie-break — with most of what used to separate clips now identical,
a tie means the measurements do not choose, and the shape is the surgeon's call.

### Where a bent clip actually sits

`pose_transform` puts the device's origin on the neck and aligns its +Z with the
neck normal, so «on the neck» means two things: the jaw's middle at that origin,
and the jaw square to that normal. A bent clip failed both, and each failure had
its own cause.

**The rotation turned the shaft into the plane, not the jaw.** A flat −90° put
the file's long axis in the neck plane — and the long axis is the shaft, so the
blades came out lifted by exactly the bend: `sin(60°)` of the jaw off-plane at
60°, two thirds at 90°. On screen the blades hovered beside the aneurysm. An
angled clip IS blades at an angle to the shaft: the blades go on the neck, the
shaft is what comes in angled. The turn now follows the JAW direction, which
lands all four series on the device's X, inside the plane.

**The centring assumed the jaw ran through the file's origin.** It does for a
straight clip and not for a bent one — the knee lifts the jaw sideways, 2.69 mm
for a 90° design — so the blades ended up in a plane *parallel* to the neck.
Right attitude, wrong height: a 13 mm jaw covered 64 % of a 6 mm neck. The middle
along the jaw axis is still `root + jaw/2` by definition (the measured centroid
is biased toward the root, because the jaw is tapered), but the offset ACROSS the
axis is now measured off the mesh, where it was being assumed to be zero.

All nine drawn configurations now span 100 % of a 6 mm neck, and
`test_the_blade_actually_closes_on_the_neck` keeps them there with the same
`plane_span` figure the plan reports as coverage.

### The clip you chose is the clip that gets made

Reported from the application: a Sugita curved stayed as the chosen device after
a NAVARRO was picked, fabricación then refused to personalise it, and the
workshop dossier printed the Sugita. Three faults met in that one symptom.

**A race in the devices panel.** The effect that preselects a default clip closed
over `sel` as it was when it ran — empty, on mount — so a pick made while
`/clips/recommendations` was still in flight was overwritten the moment it
landed. A functional update reads the current value instead, and the
preselection is what it was meant to be: a default for an empty box, never a
correction.

**The placement recorded a name, not an id.** So nothing downstream could tell a
T1 from a T4, and the manufacturing step re-derived a piece from the
measurements. Recommendation and decision could disagree in silence. The plan now
stores the `clip_id`, and both the dossier and the order form start from the clip
that was PLACED — advice loses to a decision.

**The fenestrated path had no family answer**, so a bifurcation case fell through
to a commercial clip by construction. With T4 drawn, it no longer can.

### Requesting a clip

`POST /api/clip-orders/{sid}` turns a recommendation into a real order. Most of
the form is already answered: the system knows the series, the bend, the jaw, the
tolerances and the force band, so the user is asked only what it cannot know —
who answers for the piece, how many, by when, and where it goes.

**Nothing measured is retyped.** The dangerous version of this screen is a blank
form where the surgeon re-enters the jaw length: the moment the typed number and
the STL can disagree, a workshop receives a dimension nobody derived. Changing a
computed figure is allowed — it is the surgeon's call — but it needs a reason,
and the reason is printed in our copy of the dossier next to what the system had
advised.

**A signed order is frozen.** The dimensions are copied into it, not looked up
when it is read. Re-running morphometry afterwards changes what the system would
advise today; it must not change what was ordered and sent.

**Two defects the register exposed and fixed.** The part number used to be
derived from the session and the jaw (`PR-{session}-{jaw×10}`), so two clips
ordered from one session with the same jaw and different bends got the *same*
number — on the only thread between our copy and the workshop's. And the files
had fixed names per session, so a second order overwrote the first one's STL and
dossiers. Orders now take a correlative `PR-YYYY-NNNN` and own a directory.

**Who signs.** `medico` and `admin` sign; a `residente` prepares the draft.
Signing needs a responsible surgeon, a workshop, and three declarations that the
UI may not pre-tick: the measurements are accepted, the closing force is a target
to be measured on the finished part, and the STL is geometry rather than an
approved device. When the intended use is *implant in a patient* the order also
records an authorisation reference — it does not block, it records.

**What leaves the building** is a ZIP with the STL and the workshop's dossier,
and nothing else: no patient name, no case, no session. A person downloads it and
sends it; the application mails nothing on its own.

**The order is not done until the piece is measured.** Reception demands the
measured jaw and the measured closing force — the only point at which the force
stops being a target — and a piece outside the jaw tolerance or the 120–200 g
band cannot be accepted in silence: either it is rejected, or someone states in
writing why the deviation is acceptable and that stays with the order.

**The register is a screen of its own** (`/app/pedidos`), outside the pipeline:
the pipeline walks ONE case, this crosses all of them and answers a management
question — what is ordered, and what is going stale. Reached from the top menu,
or from a patient's sheet, which opens it already filtered by that patient, so
one view serves both questions.

Two things separate it from a plain table. It **sorts by what is rotting**, not
by creation date: an order sent forty days ago with no news matters more than one
signed yesterday, and the thresholds follow the state — three weeks for a
workshop, one for a piece already in the building that nobody has accepted or
rejected. And it **surfaces pieces received out of specification**, which is
exactly what must not be buried in a list.

**Workshops are typed once**, and have a screen of their own (`/app/talleres`).
A workshop entered in an order form is saved and picked from a list next time,
but that was the ONLY way in — and the order form does not render at all when the
NAVARRO™ family cannot build the shape the case asks for, so a fenestrated case
had no door to the workshop directory, and registering the workshops of an
agreement up front meant opening an order and deleting it. Registering who
manufactures has nothing to do with whether THIS case is buildable.

Anyone may add and correct one — a surgeon placing an order needs to. Deleting is
admin-only, because a deleted workshop leaves everyone's list. Neither rewrites
history: orders copy the workshop's details at signing, so a past order still
says where it was actually sent. The screen also carries the two fields the order
form never asked for, `tax_id` and `notes`, which a real agreement needs.

**Sterilisation and marking are stated assumptions, not policy.** Nobody has yet
confirmed how this institution handles either, so the order assumes the hospital
sterilises (a machine shop rarely delivers sterile, and titanium takes steam) and
that the part number is engraved on the **body** — never on the jaw, which is the
dimension measured against the neck, and never on the spring, where a mark
concentrates stress exactly where the closing force comes from. Both assumptions
are written into the two dossiers so the workshop can contradict them before
cutting metal.

### The clip library

`clip_library/` is a global, persistent store outside `data/`, holding two kinds
of entry: `stock` clips the institution actually owns (these join the built-in
catalogue when a case is scored) and `template` manufacturing designs (which
never compete as stock — a design nobody has made is not something to reach for
in theatre).

From an uploaded mesh the store measures the **oriented** bounding box and the
volume. Everything else is declared on import, and the reason is worth knowing
because it looks automatable:

- **Closing force** is a property of the spring and the alloy. No geometry
  carries it, so a `stock` clip without one is refused rather than stored with a
  zero that would silently sink it in every ranking.
- **Shape and fenestration** could in principle be inferred, but a CAD export is
  rarely a clean closed manifold and the inference fails quietly on exactly the
  irregular meshes where it would matter. `POST /api/clip-library/measure`
  offers a hint to pre-fill the form; it is labelled a suggestion.
- **Blade width and height** cannot be separated from the jaw opening by a
  bounding box — across that axis the envelope is two blades plus the gap — so
  the stored figures are named `envelope_*`.

### What this is not

The geometric criteria are arithmetic on measured quantities. The clinical
preferences (shape per region, closing-force windows) are heuristics from Lawton
2011, Molyneux and Pierot & Wakhloo, **not validated against annotated cases** —
there is no ground truth in this project to validate a ranking against. The panel
is assistive and always shows its reasons; it does not choose a clip.

Whether a branch actually runs through the neck is not visible in the isolated
sac mesh, so "consider a fenestrated clip" is raised once as a case-level
caveat, never as a defect on each non-fenestrated clip. A warning that fires on
almost the whole catalogue stops carrying information.

---

## Navigation & Unsaved Work

The frontend uses a **data router** (`createBrowserRouter`), and the URL is the
source of truth for which screen is showing — Back/Forward, a refresh and a
shared link all land where the user expects, instead of resetting to the patient
list.

That matters because saving is manual. Leaving the pipeline throws the working
session away, so an accidental click on the logo — or a press of the browser's
Back button — used to cost an entire analysis without a word. The workspace now
marks itself dirty as soon as a step produces a result worth keeping, and:

- `useBlocker` intercepts **every** router navigation, including Back/Forward,
  and raises a confirmation dialog. A hand-rolled guard around the app's own
  click handlers could never see the browser's buttons.
- `beforeunload` covers closing the tab or reloading.
- Resuming a saved session marks it clean again. Rehydration replays the saved
  results through the same setters a real edit uses, so without this a resumed
  session asked to confirm before the user had touched anything.

The dirty flag is set inside the store's setters rather than at each call site,
so a panel added later cannot forget to do it.

---

## API Reference

149 operations under `/api`. Full spec in `frontend/openapi.json` or at `/docs` (requires a session).

**Everything except `POST /api/auth/login`, `/signup` and `/logout` requires a
token.** It travels as `Authorization: Bearer …` or as the `prospective_token`
cookie that login also sets — the browser cannot attach a header to an `` or to the requests vtk.js makes for `.vtp` meshes, and those URLs serve
patient imaging.

A `POST`/`PUT`/`PATCH`/`DELETE` under `/api/` that is authenticated **by cookie
alone** (no `Authorization` header) must also carry `X-CSRF-Token` equal to the
`prospective_csrf` cookie, which login sets readable by the page's JavaScript
(double submit, `services/csrf.py`); otherwise 403. Bearer requests are exempt:
no other page can set that header without passing CORS. So are login, signup
and logout, which a stale cookie must never block.

**Session ids are validated.** A session id arrives from outside and becomes a
path. Unvalidated, `..` WAS a valid session (`data/sessions/..` is `data/`), and
`POST /api/sessions/save` with it ran `rmtree` on `data/session_saves/..` — the
whole `data/` folder, database and audit chain included, for any signed-in
user. `services/sessions.py` now accepts only the canonical UUID that
`create_session` generates; anything else is a 404.

**Who sees which patient.** A non-admin sees the patients they created; the
rule lived only in the patients router. It is now one module
(`services/access.py`) applied to the study gallery, captures, saved sessions,
the longitudinal and follow-up endpoints, lesion confirmations and the files
under `/data`. A session not yet attached to a patient has no owner to check:
its random UUID is the key.

**`/data` serves session files only.** It used to serve the whole `data/`
folder, so `/data/prospective.db` was the entire database for any account. Only
`/data/sessions/<uuid>/…` is served now, and only when that session does not
belong to someone else's patient; everything else is a 404, for admins too.

**First login and failed logins.** The default `admin` / `admin123` account must
change its password before doing anything else (403 on every other endpoint;
the app shows a single screen for it), and an existing installation still on
`admin123` is flagged at startup. `PROSPECTIVE_ALLOW_DEFAULT_ADMIN_PASSWORD=1`
turns this off for tests and local development — never with patient data.
Five failed logins for the same user from the same address within 15 minutes
answer 429 until the oldest expires (`services/login_throttle.py`).

### Authentication & users

| Method | Endpoint | Description |
|---|---|---|
| `POST` | `/api/auth/login` | Obtain JWT (username + password) |
| `GET` | `/api/auth/me` · `/api/auth/me/photo` | Current user + avatar |
| `POST` | `/api/auth/logout` | Clear the session cookie |
| `POST` | `/api/auth/change-password` | Change your own (current password required) |
| `POST` | `/api/auth/users/{id}/reset-password` | Reset someone else's (admin) |
| `POST` | `/api/auth/signup` | Public signup (multipart: photo + CV) → *pending* |
| `GET` | `/api/auth/pending` | Pending signup requests (admin) |
| `POST` | `/api/auth/pending/{id}/approve` · `/reject` | Approve or reject (admin) |
| `GET` | `/api/auth/pending/{id}/photo` · `/cv` | Download applicant documents (admin) |
| `GET` `POST` | `/api/auth/users` | List / create users (admin) |
| `PUT` `DELETE` | `/api/auth/users/{id}` | Edit / delete, with anti-lockout guards (admin) |

### Patients, cases & imaging studies

| Method | Endpoint | Description |
|---|---|---|
| `GET` `POST` | `/api/patients` | List / create patients |
| `GET` `PUT` `DELETE` | `/api/patients/{id}` | Full record, edit, delete (cascades) |
| `POST` | `/api/patients/case` | Create patient + clinical case in one step |
| `GET` `POST` | `/api/patients/{id}/studies` | List / add clinical cases |
| `PUT` `DELETE` | `/api/patients/{id}/studies/{sid}` | Edit / delete a case |
| `GET` | `/api/patients/{id}/sessions` | Saved planning sessions of a patient |
| `GET` | `/api/studies` | Gallery: archived imaging studies (`q`, `patient_id`, `case_id`) |
| `GET` | `/api/studies/{id}/thumbnail` | Rendered preview PNG |
| `POST` | `/api/studies/cases/{case_id}/archive` | Archive a session's DICOM under a case |
| `POST` | `/api/studies/{id}/open` | Restore an archived study into a new session |

### DICOM, viewers & sessions

| Method | Endpoint | Description |
|---|---|---|
| `POST` | `/api/upload` | Upload DICOM files/folder → session + series list |
| `POST` | `/api/upload/{sid}/series/{series_id}` | Switch the active series |
| `GET` | `/api/volume/{sid}/meta` · `/raw` | Volume metadata · raw uint8 volume |
| `GET` | `/api/slice/{sid}/{plane}/{index}` | MPR slice PNG (`wc`, `ww`, optional `lower`/`upper` tint) |
| `GET` | `/api/slice-oblique/{sid}` | Oblique reslice PNG |
| `POST` | `/api/sessions/save` · `/{sid}/restore` | Durable snapshot · rehydrate |
| `GET` | `/api/sessions` | List saved sessions |
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

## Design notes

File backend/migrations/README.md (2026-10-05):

# Migraciones de la base de datos

El esquema se versiona con Alembic desde la revisión `0001_baseline`. Al
arrancar, `init_db()`:

1. crea las tablas que falten (`create_all`);
2. pasa las migraciones antiguas escritas a mano (`_migrate_*`), que llevan
   una base anterior hasta la línea base. **No se añaden más ahí**;
3. en una base recién creada, la marca con la última revisión (ya nace con el
   esquema actual); en una que ya existía, aplica las revisiones pendientes.

## Añadir un cambio

Una **tabla nueva** no necesita revisión: la crea `create_all`.

Para **cambiar una tabla que ya existe** (columna nueva, índice, datos):

```
cd backend
.venv/Scripts/python -m services.database revision "añade tal columna"
```

Eso escribe un fichero en `versions/` comparando los modelos con tu base.
Revísalo siempre antes de subirlo: en SQLite los cambios van dentro de
`op.batch_alter_table`, que copia la tabla.

Como una base nueva nace ya con la columna, la revisión solo corre en las que
existían antes; no hace falta que compruebe si la columna está.

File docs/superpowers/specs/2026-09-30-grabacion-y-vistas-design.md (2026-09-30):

# Grabación del visor y vistas ocultables — diseño

Fecha: 2026-09-30 · Estado: implementado

## Qué se pidió

1. Que el profesional pueda **grabar la pantalla de PROSPECTIVE** como hace las
   capturas, y guardar y descargar el vídeo. Usos: presentar la planificación a
   colegas, documentar el caso y docencia — los tres.
2. Poder **ocultar y volver a mostrar las reglas y marcos verdes** del HUD.
3. Poder **ocultar y volver a mostrar la franja de cortes** (axial, coronal,
   sagital y MIP), dejando solo la vista principal.

## Decisiones

- **Se graba el visor, no la pantalla.** `getDisplayMedia` graba lo que el
  usuario elija, barra superior incluida, que lleva el nombre del paciente. Un
  vídeo se reenvía sin pensarlo. Cada fotograma se compone como la captura
  (`paintFrame`, compartido con `composeCapture`): paneles visibles en su
  sitio + lecturas del HUD, sin datos del paciente.
- **Sin audio** (decisión del usuario): la voz del profesional en el estudio
  del paciente es otra cuestión.
- **Al parar, se descarga y se guarda** en el estudio de imagen como una
  captura más (`case_captures.media_type = video/*`). Sin estudio archivado,
  solo se descarga y se avisa.
- **MP4 (H.264) si el navegador lo graba** (Chrome/Edge); si no, WebM. Sin
  conversión en servidor. 2,5 Mbit/s, tope 3 min (se para sola y avisa), tope
  de 80 MB en el servidor, tipo comprobado por los bytes.
- **REGLAS oculta solo la decoración** (opción a del usuario): esquinas, cinta
  de rumbo, escalera de cortes, retícula y líneas de referencia. Se quedan las
  letras de orientación, el número de corte, las medidas y los avisos de
  seguridad (ORIENTACIÓN ASUMIDA, instrucciones de marcado).
- **CORTES y REGLAS se recuerdan en el navegador** de cada profesional
  (`localStorage`); no son datos del caso. Capturas y grabaciones salen como
  se ve el visor.

## Cómo funciona

- `captureRenderWindow` gana `grab(ctx, rect)`: dibuja la ventana de vtk.js y
  copia su lienzo a un contexto 2D **en la misma tarea**, porque vtk.js crea el
  contexto WebGL con `preserveDrawingBuffer: false`.
- `viewerRecorder.startRecording` pinta cada fotograma en un lienzo propio y lo
  graba con `MediaRecorder` desde `canvas.captureStream()`.
- **Temporizador y no `requestAnimationFrame`.** Medido en el navegador: con la
  pestaña oculta rAF no se llama nunca (0 veces en 2 s) y el vídeo salía vacío
  (20 KB para 27 s). Con `setInterval` la grabación sigue, a ~1 fps en una
  pestaña oculta y a 30 fps en una visible.
- El visor publica en el store `viewerRecording` (`read()` por fotograma +
  `state()`), una sola vez y leyendo por refs, como `captureCase`.
- Backend: `POST /api/captures/video` (multipart), `GET /api/captures/{id}/video`,
  columnas `media_type` y `duration_s` con migración `ADD COLUMN`. `/image` de
  una grabación y `/video` de una captura dan 404. El informe PDF salta los
  vídeos y el selector de capturas del informe no los ofrece.

## Verificado

- Backend: `test_grabaciones.py` (14) + suite completa.
- Frontend: grabadora con dobles, botón, galería, selector, preferencias y qué
  es decoración + suite completa.
- Navegador real (Chrome 154, sesión de Cerón): grabación de 15 s guardada en el
  estudio; ffmpeg la decodifica como H.264 1092×748 y los fotogramas enseñan la
  malla girando con el HUD y sin marcos. La grabación de prueba se borró.

## Lo que no se pudo medir

La tasa real de 30 fps: la ventana de automatización estaba oculta y el
navegador limita ahí el temporizador a una vez por segundo.

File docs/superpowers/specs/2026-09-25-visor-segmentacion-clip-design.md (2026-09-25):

# Visor clínico, segmentación tubular y mapa de calor del clip — diseño

Fecha: 2026-09-25 · Estado: borrador para revisión

## 1. Propósito

Que un profesional de salud se siente delante de PROSPECTIVE Web y el visor de
estudios se comporte como una estación radiológica: cortes que siguen a la
rueda, cuatro paneles sincronizados (tres planos y un MIP/3D), orientación
siempre visible, una malla vascular que parece lo que es —tubos— y, al colocar
un clip, una lectura en color de si ese clip abraza el cuello con la fuerza y
el tamaño que ese aneurisma pide.

Se divide en tres subproyectos que se implementan en este orden, cada uno con
su propio plan de implementación:

| # | Subproyecto | Qué entrega |
|---|---|---|
| A | Visor 2D/3D en el cliente | Scroll fluido, distribución 1+3+MIP, MIP progresivo, maniquí, sincronizar al punto |
| B | Segmentación tubular y render pulido | Malla estanca, sin hueso pegado, vasos macizos, render limpio |
| C | Mapa de calor del clip | Escalar por vértice en cuello y saco + veredicto de idoneidad del clip |

El orden importa: B produce la malla sobre la que C pinta, y A da el visor
donde B y C se ven.

## 2. Contexto medido (Case 3, 3DRA XA 384³, vóxel 0,32 mm)

| Hecho | Medida |
|---|---|
| Corte PNG en servidor | 8 ms |
| Retraso de la interfaz al hacer scroll | 90 ms de debounce + una `<img>` por corte; 15 ticks → 1 imagen |
| Segmentación media resolución (actual) | ~5 s, 12 776 vértices, 4 314 mm³, 67 aristas de borde |
| Segmentación resolución completa sin techo | 16,6 s (16 núcleos), 123 964 vértices, 11 090 mm³, base de cráneo en bloque |
| Detección | pierde los canales de calibre por encima de 40 000 vértices |
| Orientación del paciente en el DICOM | ausente (Enhanced XA sin `ImageOrientationPatient`) |
| Lesión confirmada (según captura `frontend/Estudios/aneurisma.png`) | pequeña dilatación en la horquilla de una bifurcación del tronco grueso; corresponde al candidato actual **cand-002** (x 62 · y 64 · z 63 mm). **Pendiente de confirmar por el usuario.** |

Restricciones de despliegue (dichas por el usuario): front en AWS Amplify,
back en una instancia Lightsail de 12 USD (1 vCPU, 2 GB RAM), uso por internet.
Las dos consecuencias que gobiernan el diseño:

- El navegador tiene más CPU/GPU que el servidor: todo lo interactivo
  (cortes, ventana/nivel, MIP, oblicuo) va al cliente.
- El servidor no puede tener varias copias float32 de un 384³ (226 MB cada
  una) en memoria: la segmentación trabaja por regiones y por bloques, con
  guardas de memoria explícitas, y en 1 vCPU tardará varias veces lo medido
  aquí, así que hay progreso real y no una barra indeterminada.

## 3. Subproyecto A — Visor 2D/3D en el cliente

### 3.1 Volumen en el navegador

Nuevo endpoint `GET /api/volume/{sid}/chunk/{level}/{z0}-{z1}` que devuelve un
bloque de cortes del volumen como `int16` crudo (little-endian) con gzip
(`GZipMiddleware`, umbral 1 KB). Dos niveles:

- `level=coarse`: el volumen ya existente de 192³ `uint8` (7 MB), que se pide
  entero al abrir el estudio. Con él ya se puede navegar en menos de 2 s.
- `level=full`: el volumen nativo en `int16`, en lonchas de 32 cortes en z
  (para 384³: 12 bloques de ~9,4 MB). El cliente los pide en orden de
  proximidad al corte actual y los va sustituyendo en su textura.

Para volúmenes de más de 150 M vóxeles el nivel `full` se sirve submuestreado
2× en el plano (lo dice la cabecera `X-Level-Stride`) y el cliente marca los
cortes como «resolución reducida»; no se ofrece corte del servidor a
resolución nativa en esta fase.

El cliente guarda los bloques en la Cache API con clave `sid + mtime del .npy`
para que recargar la página o reanudar no vuelva a descargar.

Meta ampliada (`GET /api/volume/{sid}/meta`): añade `direction` (cosenos de
dirección 3×3 en LPS, o `null`), `orientation_known: bool`, `origin_mm`,
y `intensity_range` robusto (p0.5–p99.9) para inicializar ventana/nivel y las
transferencias del MIP.

`dicom_loader` pasa a conservar la matriz de dirección (SimpleITK ya la lee)
y a escribirla en `_volume_meta.json`. Sin etiquetas, `direction = null`.

### 3.2 Render de cortes con vtk.js

`MprView` deja de ser una `<img>` y pasa a un `vtkImageSlice` + `vtkImageMapper`
sobre un `vtkImageData` compartido (un solo `vtkImageData` por sesión, tres
mappers apuntando a él). Ventana/nivel es una propiedad del `vtkImageProperty`
(instantáneo). El corte se cambia con `mapper.setSlice`. Arrastrar con botón
izquierdo sigue siendo ventana/nivel; botón central o `Shift`+arrastre
desplaza; rueda cambia de corte; `Ctrl`+rueda hace zoom; flechas ↑/↓ cambian
de corte; `Inicio`/`Fin` saltan a los extremos.

Cada panel de corte lleva etiquetas de orientación en los cuatro bordes
(A/P/I/D/S/I) derivadas de `direction` o, si es asumida, entre corchetes
`[A]` y en gris. Barra de escala de 10 mm abajo a la derecha. Líneas de
referencia: en cada plano se dibuja dónde cortan los otros dos (colores fijos:
axial azul, coronal verde, sagital rojo), con el crosshair actual.

El oblicuo se resuelve con `vtkImageResliceMapper` sobre el mismo
`vtkImageData`, con los mismos controles de inclinación y posición; deja de
pedir PNGs al servidor. `render_oblique_png` se conserva para el informe.

El tinte de la banda de umbral (vista previa de segmentación) se implementa
como una segunda capa `vtkImageSlice` con una función de transferencia que
solo es opaca dentro de [inferior, superior]; se actualiza sin red.

### 3.3 Distribución 1+3 y cuarto panel

Se mantiene la distribución actual (panel principal + franja de tres) y se
añade un **cuarto panel** en la franja: MIP. La franja pasa a tener cuatro
celdas del mismo ancho. Cualquier celda se puede **maximizar** con doble clic
(ocupa el panel principal y lo que había en el principal baja a la franja);
doble clic de nuevo restaura. La preferencia se guarda en `localStorage`.

El panel principal muestra por defecto lo que hoy (3D con malla o axial sin
malla). El selector «3D · Volumen · Oblicuo» de la esquina se conserva y
cambia solo el panel principal.

### 3.4 MIP progresivo

El cuarto panel es un `vtkVolume` con `vtkVolumeMapper` en modo
`MAXIMUM_INTENSITY_BLEND` sobre el mismo `vtkImageData`. Dos modos, con un
control en el propio panel:

- **Acumulado** (por defecto): el mapper lleva un plano de recorte en el eje
  del panel principal activo (por defecto z) situado en el corte actual; al
  avanzar cortes el volumen aparece; al retroceder desaparece. Un botón
  invierte el sentido (acumular desde el final).
- **Lámina**: dos planos de recorte a ±N mm del corte actual (N ajustable,
  por defecto 10 mm).

Función de transferencia «Vasos»: rampa de opacidad que empieza en el umbral
inferior de la banda de segmentación (el mismo estado `previewBand` o, si ya
hay malla, `seg.threshold_lower`), no en HU fijos. Presets existentes
(CTA, Cerebro…) quedan solo cuando `modality` es CT.

La cámara del MIP sigue la orientación del plano principal (axial → desde
superior, etc.) salvo que el usuario la rote; «Ajustar» la devuelve.

### 3.5 Maniquí de orientación

`vtkOrientationMarkerWidget` en la esquina inferior derecha del panel 3D y del
MIP. Actor compuesto: `vtkAnnotatedCubeActor` con caras A/P/D/I/S/I más una
figura humana de baja resolución (cabeza y torso, ~600 triángulos, en
`frontend/public/models/maniqui.vtp`) alineada con el cubo y con la cara
marcada. Gira con la cámara del panel en que vive.

Cuando `orientation_known = false` el maniquí se dibuja en gris con el rótulo
«orientación asumida» y aparece un control «Fijar orientación» en el visor:
el usuario elige, para el volumen tal como se ve en el axial, qué borde es
anterior y si el primer corte es superior o inferior. Se guarda en el estado
de sesión (`dicom.orientation_manual`) y a partir de ahí todos los paneles,
etiquetas y el maniquí lo usan. Con TC la dirección viene del DICOM y el
control no aparece.

### 3.6 Sincronizar todas las vistas al punto

Interruptor «Sincronizar al punto» (icono de cadena) en la barra del visor,
activado por defecto. El estado compartido es un único punto en mm de mundo
(`focusPoint`) en el store, del que se derivan el vóxel del crosshair
(`mm / spacing`, porque las mallas están en vóxel·spacing con origen 0) y el
punto focal de las cámaras 3D y MIP. Fuentes que lo mueven cuando está activo:

- clic en cualquier corte (ya existe como crosshair),
- cualquier pick 3D (cuello, ápice, medida, centro de recorte…),
- seleccionar un candidato en Detección (su `center_mm`),
- entrar en Morfometría o Dispositivos con un saco medido (su `neck_origin`),
- el botón «Centrar en la lesión» que se añade a esos dos paneles.

Efecto: los tres planos saltan al vóxel; la cámara 3D y el MIP mueven su
punto focal al punto **sin cambiar la distancia ni la orientación** (no hay
zoom automático, que desorienta), salvo «Centrar en la lesión», que además
encuadra a 30 mm.

Con el interruptor apagado el crosshair sigue enlazando solo los tres planos,
como ahora.

### 3.7 Errores y degradación

- Si el bloque `full` falla o tarda, el visor sigue con `coarse` y lo dice en
  el rótulo del panel («resolución reducida · cargando 4/12»).
- Sin WebGL2 el visor cae al modo actual (PNG del servidor) con un aviso.
- La descarga se cancela al cambiar de sesión (AbortController).

### 3.8 Pruebas

- Unitarias (vitest): conversión mm↔vóxel con y sin flip de z; derivación de
  etiquetas de orientación desde `direction` y desde la orientación manual;
  orden de petición de bloques por proximidad; estado `focusPoint` → índices
  de los tres planos.
- Backend (pytest): `chunk` devuelve el tamaño exacto y los bytes correctos
  de un volumen sintético; `stride` para volúmenes grandes; `direction` en
  meta para un CT sintético con IOP y `null` sin él.
- Manual con Case 3: 30 ticks de rueda en 1 s deben producir ≥ 25 fotogramas
  distintos (se mide con el mismo script de la revisión); MIP acumulado
  coherente con el índice; maniquí gira con la cámara.

## 4. Subproyecto B — Segmentación tubular y render pulido

### 4.1 Diagnóstico

Hoy la máscara es `banda ∩ volumen` y marching cubes va sobre un binario a
media resolución. Tres defectos con causa clara:

1. **Vasos huecos** («se ven vacíos»): el techo de la banda descarta el núcleo
   más brillante del vaso lleno de contraste, y queda una cáscara abierta.
2. **Hueso pegado** (peñasco, base de cráneo): comparte intensidad con el
   contraste; ni umbral ni «árbol principal» lo separan cuando toca al árbol.
3. **Superficie abollada y con huecos**: binario submuestreado 2× + suavizado
   corto; 67 aristas de borde; triángulos alargados.

### 4.2 Pipeline nuevo (`services/segmentation.py`, `services/vesselness.py`)

Entrada: volumen nativo (z,y,x) float32 memmap, `spacing`, banda
[inferior, superior], nivel de limpieza, nivel de suavizado.

1. **Región de interés.** Máscara gruesa `vol ≥ inferior` submuestreada 4×;
   caja envolvente dilatada 5 mm. Todo lo demás se recorta antes de cualquier
   filtro. En Case 3 la ROI es ~55 % del volumen.
2. **Relleno del núcleo.** Máscara `M0 = vol ≥ inferior` (sin techo). El techo
   deja de ser un filtro de vaso: si el usuario lo mantiene, se aplica solo
   como `vol ≤ superior` **después** del relleno de huecos 3D
   (`scipy.ndimage.binary_fill_holes`), de modo que un vaso cuyo centro supera
   el techo sigue macizo. Resultado: tubos llenos.
3. **Vesselness.** `sitk.ObjectnessMeasureImageFilter` (Frangi, objeto
   tubular, α 0,5 · β 0,5 · γ derivado del p95 de la norma del Hessiano) en
   escalas σ = {0,3; 0,6; 1,0; 1,6; 2,5} mm, calculado **por bloques en z de
   48 cortes con 8 de solape** sobre la ROI, en float32, guardando solo el
   máximo por vóxel (uint8 normalizado). Coste de memoria acotado a ~6 copias
   del bloque, no del volumen.
4. **Máscara de vaso.** `Mv = M0 ∧ (V ≥ tV)` donde `tV` es el percentil 60 de
   V dentro de `M0` (adaptativo, no una constante). Esto quita láminas y
   bloques: el Hessiano de una lámina tiene una sola dirección de alta
   curvatura y Frangi la penaliza.
5. **Histéresis por conectividad.** Semillas = componentes de
   `M0 ∧ (V ≥ p90 de V en M0)` de más de 50 mm³ (los troncos gruesos). La
   máscara final es lo conectado a una semilla dentro de `Mv ∨ (M0 ∧ V ≥ p40)`
   (crecimiento con umbral más permisivo desde un núcleo estricto). El
   usuario puede añadir una semilla pinchando (reutiliza el pick 3D existente)
   cuando una rama queda fuera; la interfaz lo dice en el mismo aviso de
   «volumen conservado» que ya existe.
6. **Cierre suave.** `binary_closing` de 1 vóxel y `binary_fill_holes` final.
7. **Superficie.** Se suaviza la máscara con gaussiana σ = 0,7 vóxel a float y
   marching cubes a iso 0,5 (superficie sub-vóxel, sin escalones). Luego
   `vtkWindowedSincPolyDataFilter` 40 iteraciones · pass band 0,05 ·
   `BoundarySmoothingOff` · `NormalizeCoordinatesOn`; `vtkFillHolesFilter`
   (hasta 4 mm); `vtkQuadricDecimation` al 60 % conservando normales;
   `vtkPolyDataNormals` con splitting off y ángulo 60°; eliminación de
   componentes < 2 mm³ (ya existe). Criterio de aceptación: 0 aristas de
   borde y relación de aspecto mediana < 1,45.
8. **Dos mallas.** `vessel_tree.vtp` (completa, para medir) y
   `vessel_tree_display.vtp` (decimada a ≤ 40 000 vértices, para visor y
   detección). La detección consume la de visualización, de modo que los
   canales de calibre vuelven a ejecutarse; la morfometría y el corte de
   cuello usan la completa. Todas las herramientas que hoy leen
   `vessel_tree.vtp` para dibujar (recorte, borrador, previa) escriben en las
   dos.
9. **Resolución completa por defecto.** La casilla se invierte: «Segmentar a
   media resolución (más rápido)» apagada por defecto. Guardas: si la ROI
   supera 90 M vóxeles se fuerza media resolución y se dice por qué.

La **vista previa** mientras se mueven los deslizadores no cambia de
algoritmo (sigue siendo umbral + top-N a ds 5/2): es para ver dónde cae la
banda, y ahora lo dice el chip.

### 4.3 Progreso

Se implementa el WebSocket `/ws/progress/{sid}` que la documentación ya
anuncia y no existe: la segmentación publica fases («ROI», «vesselness 3/8»,
«superficie», «decimación») con porcentaje. El panel muestra fase y
porcentaje. Sin WebSocket (proxy que no lo pasa) se cae a `GET
/api/progress/{sid}` cada segundo.

### 4.4 Render en vtk.js

- Material del árbol: ambient 0,15 · diffuse 0,85 · specular 0,25 · specular
  power 24 · interpolación Phong; dos luces (key al 100 % y fill al 35 % desde
  el lado opuesto) que siguen la cámara.
- Translucidez con `renderer.setUseDepthPeeling(true)` (4 pasadas), de modo
  que el árbol al 45 % no muestre artefactos de orden.
- Saco y dispositivos con `setBackfaceCulling(false)` y borde de silueta
  opcional (`vtkOutlineFilter` no; se usa un segundo actor en representación
  wireframe con opacidad 0,15 solo sobre el saco, para leer su contorno).
- Fondo negro se mantiene; se añade un degradado sutil solo en el panel 3D
  (opción en preferencias, apagada por defecto).

### 4.5 Validación en Case 3

Métricas que el plan debe registrar antes y después, sobre la misma banda:

| Métrica | Actual | Objetivo |
|---|---|---|
| Aristas de borde | 67 | 0 |
| Volumen de hueso conservado (piezas > 3 mm de espesor eq.) | bloques del peñasco | 0 piezas |
| Relación de aspecto mediana | 1,62 | < 1,45 |
| La lesión (cand-002 según la captura) aparece en la lista corta | sí (puesto 2) | sí, puesto ≤ 3 |
| Tiempo en el equipo de desarrollo | 5 s / 17 s | < 40 s |

Si en 1 vCPU el paso de vesselness supera 3 min sobre Case 3, se reduce el
número de escalas a 3 y se documenta.

### 4.6 Pruebas

- pytest con fantomas sintéticos: tubo de 2 mm con núcleo por encima del
  techo → malla estanca y volumen ± 10 % del analítico; tubo + lámina de
  0,3 mm en contacto → la lámina no sobrevive; dos tubos separados → solo
  el que tiene semilla; guardas de memoria (ROI grande → media resolución).
- `test_detector_case3.py` se amplía con la malla de visualización nueva y
  la posición confirmada de la lesión.

## 5. Subproyecto C — Mapa de calor del clip

### 5.1 Qué representa

Un escalar por vértice sobre el saco cerrado (`aneurysm_sac.vtp`) más un
anillo de vaso de 1,5 × cuello alrededor del plano, para cada colocación de
clip. Tres lecturas, una por canal, y una escala de color con leyenda:

1. **Cobertura** (categórico): vértice del contorno de cuello dentro del
   espacio entre hojas → cubierto (verde); fuera del alcance de la hoja →
   cuello residual (magenta); saco más allá de la punta de la hoja → no
   alcanzado (gris rayado).
2. **Presión estimada** (continuo): `p = F_cierre / A_contacto`, con
   `F_cierre` la fuerza nominal del catálogo (o la banda: se usa el mínimo,
   que es el caso desfavorable) y `A_contacto` el área de los triángulos del
   anillo de cuello que quedan entre las dos hojas proyectadas. Se compara
   con la ventana `force_window(neck_mm)` de `clip_selection` convertida a
   presión con la misma área: por debajo de `acceptable_lo` azul
   («insuficiente»), dentro de la óptima verde, entre óptima y aceptable
   ámbar, por encima de `acceptable_hi` rojo («exceso»). El color se aplica a
   la zona cubierta; fuera de ella manda el canal 1.
3. **Idoneidad del clip** (veredicto, no color): longitud de hoja frente a
   cuello + margen (reutiliza `clip_selection`), apertura de mordaza frente a
   espesor del cuello en el plano, fuerza frente a ventana. Se muestra en una
   tarjeta bajo el visor y en el panel de dispositivos, con el detalle
   numérico de cada criterio.

Se etiqueta siempre como **estimación geométrica**: fuerza de catálogo
repartida sobre área de contacto; no modela pared, deformación ni
deslizamiento. La simulación mecánica queda para la fase siguiente y este
diseño deja el escalar como una capa más (`ClipFieldLayer`) para que la
sustituya sin tocar el visor.

### 5.2 Backend

`POST /api/clips/field/{sid}` con las mismas colocaciones que `/clips/plan`
(se llama automáticamente después de colocar y al cambiar posición/giro con
debounce de 250 ms). Devuelve:

```json
{
  "field_mesh_url": ".../clip_field.vtp?v=…",
  "scalars": {"coverage": "uint8", "pressure_ratio": "float32"},
  "summary": {
    "covered_pct": 92.0, "residual_pct": 8.0, "unreached_pct": 0.0,
    "pressure_g_mm2": 14.3, "window_g_mm2": [10.1, 11.6, 17.4, 21.8],
    "verdict": "ok|warn|fail", "criteria": [ … como en clip_selection … ]
  }
}
```

`services/clip_field.py`: toma `aneurysm_sac.vtp`, el anillo de vaso (corte
esférico del árbol de radio 1,5 × cuello menos el saco), la geometría del
clip en mundo (`_clip_geometry_for` + `pose_transform`, ya existentes) y el
plano de cuello. Para cada vértice: distancia con signo a los dos planos de
hoja (las hojas se modelan como los dos paralelepípedos que ya construye
`make_clip_shaped`, con su trayectoria angulada o de bayoneta), proyección
sobre el eje de la hoja para saber si está dentro de su longitud, y a partir
de ahí los dos escalares. Se escribe un único `.vtp` con dos arrays de puntos.

Sin catálogo (como en la instalación revisada) la fuerza es la del clip a
fabricar (`manufacture.closing_force_g`) y el veredicto lo dice.

### 5.3 Frontend

`MeshView` admite capas con `scalarArray` y `colorMap` (`vtkColorTransferFunction`
por capa); `Viewer` añade la capa `ClipFieldLayer` cuando hay resultado y
dibuja la leyenda (barra de color con las cuatro marcas de la ventana y las
tres categorías). El interruptor «Mapa de calor» vive en la pestaña
«Colocar» y en la barra del visor; por defecto encendido al colocar.

El ensayo de colocación (`ClipRehearsal`) no cambia: el campo se calcula para
la pose final.

### 5.4 Pruebas

- pytest con un saco esférico sintético y un clip recto: cobertura 100 % con
  hoja ≥ cuello + 1 mm y `residual > 0` con hoja corta; presión ∝ 1/área;
  veredicto sigue a la ventana de fuerza.
- vitest: leyenda y colormap a partir de un `summary` fijo; la capa se
  retira al limpiar clips.
- Manual en Case 3 con el clip a fabricar: mover el clip 2 mm fuera del
  cuello debe pintar cuello residual; girarlo 90° debe cambiar la cobertura.

## 6. Cambios transversales

- `frontend/Estudios/` (109 MB de DICOM) entra en `.gitignore`; el estudio de
  prueba se documenta en el README con su ruta local.
- El texto «tarda minutos» de resolución completa se sustituye por el tiempo
  estimado a partir del tamaño del volumen y la última segmentación de la
  sesión.
- Los presets de ventana en HU se muestran solo con `modality = CT`; para XA
  se ofrecen «Auto», «Vasos» (banda) y «Todo» (p0.5–p99.9).
- El plano de cuello automático que falla («no se aísla un saco válido»)
  prueba automáticamente desplazamientos de ±1 y ±2 mm a lo largo del eje
  antes de rendirse, y dice cuál usó. Es un arreglo pequeño y entra en B.

## 6 bis. Estética: HUD de caza

Pedido por el usuario al aprobar el diseño: que el visor se lea como el
head-up display de un avión de combate. Alcance: el visor y todo lo que se
superpone a la imagen (paneles de corte, MIP, 3D, leyendas, avisos de marcado,
controles de cámara y de distribución). El resto de la aplicación (pacientes,
formularios, paneles laterales) conserva su sistema de diseño; solo hereda el
color de acento del visor para que los dos mundos no choquen.

Reglas, para que «HUD» signifique lo mismo en cada pantalla:

- **Un solo color de acento fosforescente**, `--hud: #8CFF9E` (verde HUD), con
  variante atenuada al 55 % para lo secundario; ámbar `#FFC857` para avisos
  y el rojo actual para fallos. Fondo negro puro. Contraste mínimo 4,5:1
  sobre negro. El color nunca es el único canal: cada aviso lleva texto.
- **Tipografía monoespaciada** (JetBrains Mono, ya en `assets/fonts`) para
  todo lo que es lectura de instrumento: índice de corte, W/L, medidas,
  coordenadas, porcentaje de carga. Rótulos en mayúsculas pequeñas con
  espaciado 0,08 em.
- **Trazo fino, sin rellenos.** Se retiran las píldoras redondeadas con fondo
  semitransparente. Los grupos de botones se dibujan como texto entre
  corchetes (`[ 3D ]  VOLUMEN  OBLICUO`), el activo en acento pleno y con
  subrayado de 1 px; el resto atenuado.
- **Marcas de esquina** en cada panel (cuatro ángulos de 12 px, 1 px de
  trazo) que se iluminan en el panel activo.
- **Retícula HUD** en lugar del crosshair actual: dos ejes de 1 px con hueco
  central de 14 px y marcas cada 10 mm (usa la escala real del corte), con el
  vóxel actual escrito junto al centro.
- **Escalera de cortes** en el borde derecho de cada panel de corte: cinta
  vertical con marcas y el índice actual en una ventana, como la escalera de
  altitud; se desplaza al hacer scroll. En el MIP la misma cinta marca hasta
  dónde se ha acumulado.
- **Cinta de rumbo** en el borde superior del panel 3D y del MIP: azimut y
  elevación de la cámara en grados respecto a la orientación del paciente,
  con las letras A · D · P · I en su sitio; gira con la cámara y complementa
  al maniquí.
- **Lecturas fijas por esquina**: arriba-izquierda escena y paso; arriba-
  derecha modo y distribución; abajo-izquierda índice/orientación y escala;
  abajo-derecha W/L. Sin pistas de uso permanentes («arrastra para rotar»):
  se muestran 3 s al entrar y al pulsar `?`.
- **Sin efectos que ensucien la imagen**: nada de scanlines, ruido, brillo
  ni parpadeo sobre el área de la imagen. El acento solo vive en las capas
  de superposición.
- **Mapa de calor del clip**: la barra de leyenda se dibuja como escala de
  instrumento (marcas y valores en mono, sin degradado en la propia barra;
  el degradado va en la malla).

Se implementa como una capa de componentes de superposición
(`frontend/src/vtk/hud/`: `HudFrame`, `HudReticle`, `HudLadder`,
`HudHeadingTape`, `HudReadout`, `HudToggleGroup`) con tokens en
`styles/tokens/colors.css`, y sustituye a los estilos en línea que hoy tienen
`Viewer.tsx` y `MprView.tsx`. Entra en el subproyecto A y lo usan B y C.

## 7. Fuera de alcance

Simulación mecánica de pared y clip (fase siguiente); soporte de más de un
estudio por sesión; cambios en informe PDF más allá de incluir la captura del
mapa de calor; catálogo de clips (vacío en esta instalación).

## 8. Riesgos

| Riesgo | Mitigación |
|---|---|
| Lightsail 1 vCPU/2 GB no aguanta vesselness a resolución completa | ROI + bloques + guardas; medir en una instancia igual antes de cerrar B |
| 113 MB de volumen por internet | Coarse primero, bloques por proximidad, Cache API, gzip; stride 2 en TC grandes |
| Un solo caso con lesión conocida | Fantomas sintéticos para cada regla; la validación clínica queda declarada como pendiente |
| Orientación asumida en 3DRA | Maniquí en gris y ajuste manual guardado en sesión |

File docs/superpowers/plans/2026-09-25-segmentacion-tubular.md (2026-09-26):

# Segmentación tubular y render pulido — plan de implementación

> **For agentic workers:** REQUIRED SUB-SKILL: Use superpowers:subagent-driven-development (recommended) or superpowers:executing-plans to implement this plan task-by-task. Steps use checkbox (`- [ ]`) syntax for tracking.

**Goal:** Que la segmentación produzca una vasculatura maciza, sin hueso pegado y sin huecos —tubos que se puedan medir y clipar— con progreso real durante el cálculo, y que el visor la pinte con luz y translucidez limpias.

**Architecture:** Una máscara vascular nueva en el backend: núcleo relleno (el techo ya no vacía los vasos), tubularidad de Frangi calculada por lonchas para acotar memoria, semillas en los troncos gruesos, crecimiento por histéresis, recuperación de pared y sacos a 3 mm con veto de láminas (hueso) y superficie sub-vóxel estanca. La detección decima en memoria por encima de 40 000 vértices para recuperar sus canales de calibre. Un módulo de progreso en memoria alimenta un WebSocket y un GET de respaldo. El frontend añade el método, los parámetros y el progreso al panel de segmentación y pule materiales, luces y translucidez en el visor 3D.

**Tech Stack:** FastAPI, NumPy, SciPy, SimpleITK 2.5 (`ObjectnessMeasureImageFilter`), VTK 9.7 (backend); React 19 + TypeScript + vtk.js 36.2.1 (frontend); pytest, vitest.

**Spec:** `docs/superpowers/specs/2026-09-25-visor-segmentacion-clip-design.md` (sección 4 y punto 6 «plano de cuello» y «rango de intensidad»).

## Global Constraints

- Servidor de 1 vCPU / 2 GB: la tubularidad se calcula por **lonchas de 64 cortes con 12 de solape**, nunca sobre el volumen entero; ninguna fase mantiene más de ~4 copias de una loncha. Guarda: si el volumen supera **90 M vóxeles** se segmenta a media resolución y se dice por qué.
- Escalas de Frangi **σ = {0,4; 0,7; 1,2; 2,0} mm**, α = 0,5, β = 0,5, γ = 0,1 × (p99,9 − p50 de la intensidad), objeto brillante, `ScaleObjectnessMeasure` activo, tubularidad = máximo entre escalas. Lámina (veto de hueso) con el mismo filtro y `ObjectDimension = 2`. Medido en Case 3 (384³, 16 núcleos): 2,4–2,9 s por escala sobre el volumen entero.
- Máscara: relleno 3D del núcleo ANTES del techo; puerta tubular en el **percentil 60** de la tubularidad dentro de la máscara de umbral, que **solo mide** (`stats.core_vox` y `thresholds.gate`, la cifra de núcleo que se publica) y no filtra nada: lo que recorta la máscara son las semillas y el crecimiento, que umbralizan la tubularidad por su cuenta; `gate_pctl` se conserva como parámetro de esa cifra, y por eso moverlo no cambia la máscara (Task 11); semillas en el **percentil 90** con **≥ 50 mm³**; crecimiento en el **percentil 40**; recuperación geodésica a **3 mm** con veto de lámina; cierre de 1 vóxel y relleno final.
- Superficie: la máscara se rodea de un vóxel vacío (tapa las salidas por el borde del volumen, origen corrido un espaciado), gaussiana σ = 0,7 vóxel sobre la máscara en float, marching cubes en 0,5, `vtkWindowedSincPolyDataFilter` 40 iteraciones / pass band 0,05 / `BoundarySmoothingOff` / `NormalizeCoordinatesOn`, `vtkFillHolesFilter` hasta 4 mm, `vtkDecimatePro` 45 % con `PreserveTopologyOn` / `SplittingOff` / `BoundaryVertexDeletionOff` (solo en `mask_to_surface`; el pipeline clásico y `decimate_to` siguen con `vtkQuadricDecimation`), normales sin splitting (60°), islas < 2 mm³ fuera. Criterio: **0 aristas de borde** y relación de aspecto mediana **< 1,45**. Validado en Task 11 (`backend/scripts/validate_case3.py`): la decimación cuadrática al 60 % abría la malla (Case 3: 25 aristas de borde, 20 no-variedad, aspecto 1,58, cuando antes de decimar había 0 y 1,20); ninguno de los mandos permitidos (`fill_holes_mm` 6, `min_island_mm3` 5, `reclaim_mm` 2,5 / 3,5, `gate_pctl` 55 / 65) lo arreglaba, y por decisión del controlador se cambió a `vtkDecimatePro` 45 %. Valores finales: `decimation` 0,45, `fill_holes_mm` 4, `min_island_mm3` 2, `reclaim_mm` 3, `gate_pctl` 60, `PLATE_RATIO` 300, `WALL_MM` 0,75. Case 3: 0 aristas de borde (2 no-variedad, aceptadas; `surface_quality` las cuenta en `non_manifold_edges`), aspecto 1,43, 107 176 vértices, 0 piezas de hueso, máscara + superficie 9,0 s (34,1 s con Frangi).
- Un solo fichero de malla (`vessel_tree.vtp`, completa); la detección decima EN MEMORIA: calibre y cociente sobre ≤ 40 000 vértices y la curvatura sobre ≤ 80 000 (Task 11 bis); morfometría, saco y dispositivos usan la completa.
- Resolución completa por defecto; la casilla pasa a ser «Segmentar a media resolución (más rápido)».
- Progreso: `GET /api/progress/{sid}` siempre; `WS /ws/progress/{sid}?token=` cuando el proxy lo permite; fases con porcentaje.
- Render: ambient 0,15 · diffuse 0,85 · specular 0,25 · specular power 24; dos luces (key 100 %, fill 35 % opuesta) que siguen la cámara; `setUseDepthPeeling(true)` con 4 pasadas; contorno del saco con un casco invertido (la misma malla un 4 % mayor, caras delanteras descartadas).
- Copia de interfaz y mensajes de commit en español. `tsc -b`, `vitest run` y `pytest` (sin fallos NUEVOS respecto a la lista base del repositorio: 38 preexistentes) en verde en cada commit.
- La lesión confirmada de Case 3 (cand-002, x 62 · y 64 · z 63 mm) debe seguir en la lista corta de detección en el puesto ≤ 3. **Tras la Task 11 no se cumplía** (malla tubular nativa: puesto 13, 12 con «solo el árbol») y fue el objetivo de la Task 11 bis. Resultado de la Task 11 bis, con la curvatura sobre una copia de 80 000 vértices, el orden por mejor puesto y las regiones de curvatura que tocan una cara de la caja de la malla (las tapas del borde del volumen, tolerancia 1 mm) al final: **2.º con «solo el árbol», 2.º con la malla completa**, y 3.º en la malla de umbral de 12 800 vértices (el mismo que antes de la tarea); detección 9,6–9,9 s (antes 18,6–19,3 s). Todo eso es **a resolución nativa**. La revisión final midió la malla tubular a media resolución, que es la que produce una instancia de 2 GB con Case 3 (10 594 vértices, «solo el árbol»): ahí la lesión sale **5.ª**, solo por el cociente, y el objetivo no se cumple. Queda documentado en el README (recomendación: instancia de 4 GB o `PROSPECTIVE_MEM_BUDGET_MB`); mejorar la media resolución es una tarea aparte.

## Review Focus

1. Un volumen donde la banda no captura ninguna semilla ≥ 50 mm³ (contraste pobre): la app debe decirlo y caer a la máscara de umbral, no devolver una malla vacía sin explicación. → test en Task 3 (`test_sin_semillas_cae_al_umbral_y_lo_dice`).
2. Un aneurisma sacular (bulto no tubular) pegado a un vaso: el crecimiento por tubularidad lo recorta y la recuperación de 3 mm lo devuelve entero. → test en Task 3 (`test_un_saco_pegado_al_tubo_se_conserva`).
3. Una lámina de hueso en contacto con el vaso: la recuperación no la vuelve a meter (veto de lámina). → test en Task 3 (`test_una_lamina_en_contacto_no_vuelve_con_la_recuperacion`).
4. Progreso cuando el WebSocket no llega (proxy, Amplify): el panel debe seguir mostrando fase y porcentaje por GET. → test en Task 8 (`vuelve al GET cuando el WebSocket falla`).
5. Una segmentación que tarda minutos en 1 vCPU no puede bloquear las demás peticiones: cada fase corre en el executor y publica progreso. → test en Task 6 (`test_el_progreso_avanza_por_fases_durante_la_segmentacion`).

## Estructura de archivos

Backend (crear): `services/progress.py`, `routers/progress.py`, `services/vesselness.py`, `services/vascular_mask.py`, `test_progress.py`, `test_vesselness.py`, `test_vascular_mask.py`, `test_surface.py`, `test_segment_tubular.py`.
Backend (modificar): `services/segmentation.py` (superficie y decimación), `routers/segment.py` (método tubular, fases, guardas, resultado), `models/segmentation.py`, `routers/detect.py` (decimación para detección, reintento del plano de cuello), `routers/preprocess.py` (meta recalculada), `main.py` (router de progreso).
Frontend (crear): `src/api/progress.ts` (+ test), `src/components/segmentation/SegmentProgress.tsx`, `src/components/segmentation/TubularControls.tsx` (+ test).
Frontend (modificar): `src/api/types.ts`, `src/api/client.ts`, `src/components/segmentation/SegmentPanel.tsx` (+ test), `src/vtk/MeshView.tsx`, `vite.config.ts` (proxy WS), `README.md`.

---

### Task 1: Progreso por sesión: servicio, GET y WebSocket

**Files:**
- Create: `backend/services/progress.py`, `backend/routers/progress.py`, `backend/test_progress.py`
- Modify: `backend/main.py` (registrar el router; el WS no pasa por la dependencia de auth de los routers privados y valida el token él mismo)

**Interfaces:**
- Produces: `progress.start(session_id: str) -> None`, `progress.update(session_id, phase: str, pct: float) -> None`, `progress.finish(session_id, ok: bool, message: str = "") -> None`, `progress.get(session_id) -> dict | None` con `{"phase": str, "pct": float, "running": bool, "ok": bool | None, "message": str, "updated_at": float}`.
- Produces: `GET /api/progress/{sid}` → ese dict (404 si la sesión no existe; `{"running": false, "phase": "", "pct": 0}` si nunca se lanzó nada). `WS /ws/progress/{sid}?token=<jwt>` → un JSON por cambio (poll interno cada 250 ms), cierra al terminar; 4401 si el token no vale.

- [ ] **Step 1: Tests que fallan**

```python
# backend/test_progress.py
"""Progreso por sesión: memoria del proceso, GET y WebSocket."""
from __future__ import annotations

import time
from fastapi.testclient import TestClient

from main import app
from services import progress
from services.sessions import create_session
from services.auth_service import create_access_token

client = TestClient(app, raise_server_exceptions=True)

class TestServicio:
    def test_empieza_vacio_y_avanza_por_fases(self):
        sid = create_session()
        assert progress.get(sid) is None
        progress.start(sid)
        p = progress.get(sid)
        assert p["running"] is True and p["pct"] == 0.0 and p["phase"] == ""
        progress.update(sid, "tubularidad 2/4", 35.0)
        p = progress.get(sid)
        assert p["phase"] == "tubularidad 2/4" and p["pct"] == 35.0
        progress.finish(sid, ok=True)
        p = progress.get(sid)
        assert p["running"] is False and p["ok"] is True and p["pct"] == 100.0

    def test_finish_con_error_guarda_el_mensaje(self):
        sid = create_session()
        progress.start(sid)
        progress.finish(sid, ok=False, message="sin memoria")
        p = progress.get(sid)
        assert p["ok"] is False and p["message"] == "sin memoria"

    def test_el_porcentaje_se_acota_a_0_100(self):
        sid = create_session()
        progress.start(sid)
        progress.update(sid, "x", 140.0)
        assert progress.get(sid)["pct"] == 100.0
        progress.update(sid, "x", -3.0)
        assert progress.get(sid)["pct"] == 0.0

class TestGet:
    def test_sin_progreso_devuelve_parado(self):
        sid = create_session()
        r = client.get(f"/api/progress/{sid}")
        assert r.status_code == 200
        assert r.json()["running"] is False and r.json()["pct"] == 0

    def test_sesion_inexistente_404(self):
        assert client.get("/api/progress/no-existe").status_code == 404

    def test_refleja_el_servicio(self):
        sid = create_session()
        progress.start(sid); progress.update(sid, "superficie", 80.0)
        r = client.get(f"/api/progress/{sid}")
        assert r.json()["phase"] == "superficie" and r.json()["pct"] == 80.0

class TestWebSocket:
    def test_emite_cambios_y_cierra_al_terminar(self):
        sid = create_session()
        token = create_access_token(subject="admin")
        progress.start(sid)
        with client.websocket_connect(f"/ws/progress/{sid}?token={token}") as ws:
            first = ws.receive_json()
            assert first["running"] is True
            progress.update(sid, "máscara", 50.0)
            msg = ws.receive_json()
            assert msg["phase"] == "máscara" and msg["pct"] == 50.0
            progress.finish(sid, ok=True)
            last = ws.receive_json()
            assert last["running"] is False and last["ok"] is True

    def test_token_invalido_cierra_con_4401(self):
        sid = create_session()
        from starlette.websockets import WebSocketDisconnect
        try:
            with client.websocket_connect(f"/ws/progress/{sid}?token=malo") as ws:
                ws.receive_json()
            assert False, "debía cerrar"
        except WebSocketDisconnect as exc:
            assert exc.code == 4401
```

- [ ] **Step 2: Ver que falla**

Run: `cd backend && .venv\Scripts\python -m pytest test_progress.py -q`
Expected: FAIL (`ImportError: cannot import name 'progress'`).

- [ ] **Step 3: Servicio**

```python
# backend/services/progress.py
"""Progreso de trabajos largos, por sesión, en memoria del proceso.

Una segmentación tubular en 1 vCPU tarda minutos, y una barra indeterminada no
dice si el servidor sigue vivo. Esto guarda fase y porcentaje para que el GET
y el WebSocket los enseñen. Vive en memoria: con un solo proceso uvicorn es
exacto, y si el proceso se reinicia el progreso desaparece con el trabajo.
"""
from __future__ import annotations

import threading
import time

_lock = threading.Lock()
_state: dict[str, dict] = {}

def start(session_id: str) -> None:
    with _lock:
        _state[session_id] = {
            "phase": "", "pct": 0.0, "running": True, "ok": None,
            "message": "", "updated_at": time.time(),
        }

def update(session_id: str, phase: str, pct: float) -> None:
    with _lock:
        s = _state.get(session_id)
        if s is None or not s["running"]:
            return
        s["phase"] = phase
        s["pct"] = float(min(100.0, max(0.0, pct)))
        s["updated_at"] = time.time()

def finish(session_id: str, ok: bool, message: str = "") -> None:
    with _lock:
        s = _state.get(session_id)
        if s is None:
            return
        s.update(running=False, ok=bool(ok), message=message,
                 pct=100.0 if ok else s["pct"], updated_at=time.time())

def get(session_id: str) -> dict | None:
    with _lock:
        s = _state.get(session_id)
        return dict(s) if s is not None else None
```

- [ ] **Step 4: Router**

```python
# backend/routers/progress.py
"""Progreso de la sesión: GET siempre, WebSocket cuando el proxy lo deja pasar."""
from __future__ import annotations

import asyncio

from fastapi import APIRouter, HTTPException, WebSocket, WebSocketDisconnect

from services import progress
from services.auth_service import user_for_token
from services.database import SessionLocal
from services.sessions import session_exists

router = APIRouter(prefix="/api", tags=["progress"])
ws_router = APIRouter(tags=["progress"])

_IDLE = {"phase": "", "pct": 0.0, "running": False, "ok": None, "message": "", "updated_at": 0.0}

@router.get("/progress/{session_id}", summary="Fase y porcentaje del trabajo en curso")
async def get_progress(session_id: str) -> dict:
    if not session_exists(session_id):
        raise HTTPException(status_code=404, detail=f"Session '{session_id}' not found")
    return progress.get(session_id) or dict(_IDLE)

@ws_router.websocket("/ws/progress/{session_id}")
async def ws_progress(websocket: WebSocket, session_id: str, token: str = "") -> None:
    # El navegador no puede mandar Authorization en un WebSocket: el JWT va en
    # la query y se valida igual que en el guard de /data.
    db = SessionLocal()
    try:
        user = user_for_token(db, token)
    finally:
        db.close()
    if user is None or not session_exists(session_id):
        await websocket.close(code=4401)
        return
    await websocket.accept()
    last: dict | None = None
    try:
        while True:
            cur = progress.get(session_id) or dict(_IDLE)
            if cur != last:
                await websocket.send_json(cur)
                last = cur
                if not cur["running"] and cur["ok"] is not None:
                    break
            await asyncio.sleep(0.25)
    except WebSocketDisconnect:
        return
    await websocket.close()
```

En `backend/main.py`, junto a los demás routers privados, incluye `progress.router` con la misma dependencia de auth que los otros, y `progress.ws_router` SIN esa dependencia (`app.include_router(progress.ws_router)`), con un comentario que diga por qué (el WS valida el token en la query). Comprueba en `main.py` cómo se llama la dependencia de guardia (búscala con `grep -n "include_router" main.py`).

- [ ] **Step 5: Ejecutar**

Run: `cd backend && .venv\Scripts\python -m pytest test_progress.py -v`
Expected: 8 PASS. Si `test_token_invalido_cierra_con_4401` recibe `WebSocketDisconnect` con otro código, comprueba que el `close(code=4401)` se llama ANTES de `accept()` (Starlette lo permite: responde 403 en el handshake; en ese caso el test debe aceptar `exc.code in (4401, 1000)` y decirlo en un comentario).

- [ ] **Step 6: Commit**

```bash
git add backend/services/progress.py backend/routers/progress.py backend/test_progress.py backend/main.py
git commit -m "El progreso de un trabajo largo se puede leer por GET y por WebSocket"
```

---

### Task 2: Tubularidad y laminaridad por lonchas

**Files:**
- Create: `backend/services/vesselness.py`, `backend/test_vesselness.py`

**Interfaces:**
- Produces: `objectness_max(volume: np.ndarray, spacing: tuple[float, float, float], *, dimension: int, scales_mm: tuple[float, ...] = SCALES_MM, gamma: float | None = None, slab: int = 64, overlap: int = 12, on_progress: Callable[[int, int], None] | None = None) -> np.ndarray` (float32, misma forma que `volume`; `dimension` 1 = tubo, 2 = lámina, 0 = blob).
- Produces: `SCALES_MM = (0.4, 0.7, 1.2, 2.0)`, `auto_gamma(volume) -> float` (= 0,1 × (p99,9 − p50), mínimo 1,0).
- Produces: `synthetic_tube(shape, spacing, radius_mm, value) -> np.ndarray` y `synthetic_plate(...)` en `test_vesselness.py` (los reutiliza Task 3).

- [ ] **Step 1: Tests que fallan**

```python
# backend/test_vesselness.py
"""Frangi por lonchas: tubos altos, láminas bajas, y la loncha no cambia el resultado."""
from __future__ import annotations

import numpy as np
import pytest

from services.vesselness import SCALES_MM, auto_gamma, objectness_max

SP = (0.5, 0.5, 0.5)

def synthetic_tube(shape=(48, 48, 48), spacing=SP, radius_mm=1.5, value=1000.0, axis=0):
    """Un cilindro brillante a lo largo de `axis` sobre fondo 0."""
    z, y, x = np.mgrid[0:shape[0], 0:shape[1], 0:shape[2]].astype(np.float32)
    c = [s / 2 for s in shape]
    coords = [z, y, x]
    del coords[axis]
    cc = [c[i] for i in range(3) if i != axis]
    sp = [spacing[i] for i in range(3) if i != axis]
    d2 = ((coords[0] - cc[0]) * sp[0]) ** 2 + ((coords[1] - cc[1]) * sp[1]) ** 2
    return np.where(d2 <= radius_mm ** 2, value, 0.0).astype(np.float32)

def synthetic_plate(shape=(48, 48, 48), spacing=SP, thickness_mm=0.5, value=1000.0):
    """Una lámina brillante en el plano z = centro."""
    vol = np.zeros(shape, dtype=np.float32)
    half = max(1, int(round(thickness_mm / spacing[0] / 2)))
    zc = shape[0] // 2
    vol[zc - half:zc + half + 1] = value
    return vol

class TestFormas:
    def test_un_tubo_tiene_tubularidad_alta_en_su_eje_y_baja_fuera(self):
        vol = synthetic_tube()
        v = objectness_max(vol, SP, dimension=1)
        assert v.shape == vol.shape and v.dtype == np.float32
        centro = v[24, 24, 24]
        fuera = v[24, 4, 4]
        assert centro > 0 and fuera < centro * 0.05

    def test_una_lamina_puntua_como_lamina_y_no_como_tubo(self):
        vol = synthetic_plate()
        tubo = objectness_max(vol, SP, dimension=1)
        lamina = objectness_max(vol, SP, dimension=2)
        assert lamina[24, 24, 24] > 5 * tubo[24, 24, 24]

    def test_gamma_automatica_sale_de_la_intensidad(self):
        vol = synthetic_tube(value=2000.0)
        assert auto_gamma(vol) == pytest.approx(0.1 * (np.percentile(vol, 99.9) - np.percentile(vol, 50)), rel=1e-3)
        assert auto_gamma(np.zeros((4, 4, 4), np.float32)) == 1.0

class TestLonchas:
    def test_las_lonchas_no_dejan_costuras(self):
        vol = synthetic_tube(shape=(80, 40, 40), axis=0)
        entero = objectness_max(vol, SP, dimension=1, slab=1000, overlap=0)
        por_lonchas = objectness_max(vol, SP, dimension=1, slab=20, overlap=8)
        np.testing.assert_allclose(por_lonchas, entero, rtol=1e-3, atol=1e-3)

    def test_informa_del_progreso_por_loncha(self):
        vol = synthetic_tube(shape=(60, 32, 32))
        seen: list[tuple[int, int]] = []
        objectness_max(vol, SP, dimension=1, slab=20, overlap=4, on_progress=lambda i, n: seen.append((i, n)))
        assert seen[0] == (1, 3) and seen[-1] == (3, 3)

    def test_las_escalas_por_defecto_son_las_del_diseno(self):
        assert SCALES_MM == (0.4, 0.7, 1.2, 2.0)
```

- [ ] **Step 2: Ver que falla**

Run: `cd backend && .venv\Scripts\python -m pytest test_vesselness.py -q`
Expected: FAIL (módulo inexistente).

- [ ] **Step 3: Implementación**

```python
# backend/services/vesselness.py
"""Tubularidad (y laminaridad) de Frangi, calculada por lonchas.

Por qué existe: el umbral no separa el hueso del contraste —comparten brillo—,
pero un vaso es un tubo y el peñasco es una lámina o un bloque. El Hessiano lo
distingue. SimpleITK trae el filtro (ObjectnessMeasureImageFilter), que espera
la imagen ya suavizada a cada escala y calcula el Hessiano por diferencias.

Por qué por lonchas: sobre 384³ en float32 cada copia son 226 MB y el filtro
hace varias; en el servidor de 2 GB eso no cabe. Con lonchas de 64 cortes y 12
de solape (σ máx 2 mm ≈ 6 vóxeles a 0,32 mm) la memoria queda acotada y el
resultado es el mismo que entero — hay un test que lo comprueba.
"""
from __future__ import annotations

from typing import Callable

import numpy as np

SCALES_MM: tuple[float, ...] = (0.4, 0.7, 1.2, 2.0)
ALPHA, BETA = 0.5, 0.5

def auto_gamma(volume: np.ndarray) -> float:
    """γ de Frangi a partir del rango de intensidad: 0,1 × (p99,9 − p50).

    Medido en Case 3 (rango ≈ 5 100): γ ≈ 510 separa vasos de ruido; el 5,0 de
    ITK está pensado para imágenes normalizadas y aquí lo saturaba todo.
    """
    flat = volume.reshape(-1)
    if flat.size > 4_000_000:
        flat = flat[:: int(flat.size // 4_000_000) + 1]
    span = float(np.percentile(flat, 99.9) - np.percentile(flat, 50.0))
    return max(1.0, 0.1 * span)

def _objectness_slab(slab: np.ndarray, spacing_xyz: tuple[float, float, float],
                     dimension: int, scales_mm: tuple[float, ...], gamma: float) -> np.ndarray:
    import SimpleITK as sitk

    img = sitk.GetImageFromArray(np.ascontiguousarray(slab, dtype=np.float32))
    img.SetSpacing(spacing_xyz)
    best: np.ndarray | None = None
    for sigma in scales_mm:
        smooth = sitk.SmoothingRecursiveGaussian(img, float(sigma))
        f = sitk.ObjectnessMeasureImageFilter()
        f.SetObjectDimension(int(dimension))
        f.SetBrightObject(True)
        f.SetAlpha(ALPHA)
        f.SetBeta(BETA)
        f.SetGamma(float(gamma))
        f.SetScaleObjectnessMeasure(True)
        v = sitk.GetArrayFromImage(f.Execute(smooth)).astype(np.float32, copy=False)
        best = v if best is None else np.maximum(best, v, out=best)
        del smooth, v
    assert best is not None
    return best

def objectness_max(
    volume: np.ndarray,
    spacing: tuple[float, float, float],
    *,
    dimension: int,
    scales_mm: tuple[float, ...] = SCALES_MM,
    gamma: float | None = None,
    slab: int = 64,
    overlap: int = 12,
    on_progress: Callable[[int, int], None] | None = None,
) -> np.ndarray:
    """Máximo entre escalas de la medida de objeto `dimension`, por lonchas en z.

    `spacing` es (sz, sy, sx) como en el resto del backend; SimpleITK quiere
    (sx, sy, sz).
    """
    if gamma is None:
        gamma = auto_gamma(volume)
    nz = int(volume.shape[0])
    out = np.zeros(volume.shape, dtype=np.float32)
    starts = list(range(0, nz, slab))
    n = len(starts)
    spacing_xyz = (float(spacing[2]), float(spacing[1]), float(spacing[0]))
    for i, z0 in enumerate(starts, start=1):
        z1 = min(nz, z0 + slab)
        a, b = max(0, z0 - overlap), min(nz, z1 + overlap)
        v = _objectness_slab(np.asarray(volume[a:b]), spacing_xyz, dimension, scales_mm, gamma)
        out[z0:z1] = v[z0 - a:z1 - a]
        del v
        if on_progress:
            on_progress(i, n)
    return out
```

- [ ] **Step 4: Ejecutar y medir**

Run: `cd backend && .venv\Scripts\python -m pytest test_vesselness.py -v`
Expected: PASS. Si `test_las_lonchas_no_dejan_costuras` falla en los bordes por la respuesta del suavizado recursivo cerca del límite de la loncha, sube el `overlap` del test a 12 y comprueba que con solape ≥ 3σ máximo (6 vóxeles a 0,5 mm) la diferencia queda por debajo de `atol=1e-3`; anota en el informe el solape mínimo que lo cumple.

Mide además sobre Case 3 (sesión `c80edc28-f42d-40f6-b2e2-a882c84fbe02`, `meshes/_volume.npy`) el tiempo de `objectness_max(vol, spacing, dimension=1)` con lonchas de 64 y anótalo en el informe (referencia: 10,7 s entero, 16 núcleos).

- [ ] **Step 5: Commit**

```bash
git add backend/services/vesselness.py backend/test_vesselness.py
git commit -m "Tubularidad de Frangi por lonchas: la memoria queda acotada y el resultado no cambia"
```

---

### Task 3: La máscara vascular

**Files:**
- Create: `backend/services/vascular_mask.py`, `backend/test_vascular_mask.py`

**Interfaces:**
- Consumes: `objectness_max`, `auto_gamma` (Task 2); `synthetic_tube`/`synthetic_plate` de `test_vesselness.py`.
- Produces:

```python
@dataclass
class MaskParams:
    lower: float
    upper: float = 0.0            # 0 = sin techo
    gate_pctl: float = 60.0       # solo mide core_vox (la puerta no filtra)
    seed_pctl: float = 90.0
    grow_pctl: float = 40.0
    seed_min_mm3: float = 50.0
    reclaim_mm: float = 3.0
    plate_veto: bool = True
    closing_iter: int = 1

@dataclass
class MaskResult:
    mask: np.ndarray              # bool (z, y, x)
    stats: dict                   # ver abajo
    fallback: bool                # True cuando no hubo semillas y se devolvió el umbral

def build_vascular_mask(volume, spacing, params, *, vesselness=None, plateness=None, on_progress=None) -> MaskResult
```

`stats` lleva: `m0_vox`, `core_vox` (vóxeles de M0 sobre la puerta: solo una cifra, no filtra), `seeds`, `grow_components`, `kept_components`, `reclaimed_vox`, `vetoed_vox`, `final_vox`, `kept_fraction` (final/m0), `thresholds` (`gate`, `seed`, `grow`).

- [ ] **Step 1: Tests que fallan**

```python
# backend/test_vascular_mask.py
"""La máscara vascular: núcleo relleno, hueso fuera, sacos dentro."""
from __future__ import annotations

import numpy as np
from scipy import ndimage

from services.vascular_mask import MaskParams, build_vascular_mask
from test_vesselness import SP, synthetic_plate, synthetic_tube

def _sphere(shape, spacing, center, radius_mm, value):
    z, y, x = np.mgrid[0:shape[0], 0:shape[1], 0:shape[2]].astype(np.float32)
    d2 = ((z - center[0]) * spacing[0]) ** 2 + ((y - center[1]) * spacing[1]) ** 2 + ((x - center[2]) * spacing[2]) ** 2
    return np.where(d2 <= radius_mm ** 2, value, 0.0).astype(np.float32)

class TestNucleo:
    def test_un_tubo_con_el_centro_por_encima_del_techo_sale_macizo(self):
        vol = synthetic_tube(shape=(64, 48, 48), radius_mm=2.0, value=1000.0)
        core = synthetic_tube(shape=(64, 48, 48), radius_mm=0.8, value=3000.0)
        vol = np.maximum(vol, core)
        r = build_vascular_mask(vol, SP, MaskParams(lower=500.0, upper=2000.0))
        # Con el techo aplicado ANTES del relleno el centro quedaría hueco.
        assert r.mask[32, 24, 24]
        assert not r.fallback
        assert r.stats["final_vox"] >= 0.95 * (vol >= 500).sum()

class TestHueso:
    def test_una_lamina_suelta_no_entra(self):
        vol = np.maximum(synthetic_tube(shape=(64, 64, 64), radius_mm=2.0), 0)
        vol[8:11, :, :] = 1000.0          # lámina lejos del tubo
        r = build_vascular_mask(vol, SP, MaskParams(lower=500.0))
        assert not r.mask[9, 32, 32]
        assert r.mask[32, 32, 32]

    def test_una_lamina_en_contacto_no_vuelve_con_la_recuperacion(self):
        vol = synthetic_tube(shape=(64, 64, 64), radius_mm=2.0)
        vol[31:33, 20:64, 34:64] = 1000.0  # lámina que toca el tubo por un lado
        con = build_vascular_mask(vol, SP, MaskParams(lower=500.0, plate_veto=True))
        sin = build_vascular_mask(vol, SP, MaskParams(lower=500.0, plate_veto=False))
        lamina = np.zeros_like(vol, dtype=bool); lamina[31:33, 20:64, 44:64] = True
        assert con.mask[lamina].mean() < 0.15
        assert sin.mask[lamina].mean() > con.mask[lamina].mean()
        assert con.mask[32, 32, 32]

class TestSaco:
    def test_un_saco_pegado_al_tubo_se_conserva(self):
        vol = synthetic_tube(shape=(64, 64, 64), radius_mm=1.5)
        saco = _sphere((64, 64, 64), SP, (32, 32 + 6, 32), 3.0, 1000.0)   # bola pegada al lado
        vol = np.maximum(vol, saco)
        r = build_vascular_mask(vol, SP, MaskParams(lower=500.0, reclaim_mm=3.0))
        assert r.mask[saco > 0].mean() > 0.9
        r0 = build_vascular_mask(vol, SP, MaskParams(lower=500.0, reclaim_mm=0.0))
        assert r0.mask[saco > 0].mean() < r.mask[saco > 0].mean()

class TestSemillas:
    def test_sin_semillas_cae_al_umbral_y_lo_dice(self):
        vol = synthetic_tube(shape=(32, 32, 32), radius_mm=0.6, value=1000.0)  # demasiado fino para 50 mm³
        r = build_vascular_mask(vol, SP, MaskParams(lower=500.0, seed_min_mm3=50.0))
        assert r.fallback is True
        assert r.stats["seeds"] == 0
        np.testing.assert_array_equal(r.mask, ndimage.binary_fill_holes(vol >= 500.0))

    def test_una_rama_suelta_sin_semilla_se_descarta(self):
        vol = synthetic_tube(shape=(64, 64, 64), radius_mm=2.0)
        rama = synthetic_tube(shape=(64, 64, 64), radius_mm=0.9, axis=2)
        rama[:, :, :] = np.roll(rama, 20, axis=1)      # tubo fino separado del grueso
        vol = np.maximum(vol, rama)
        r = build_vascular_mask(vol, SP, MaskParams(lower=500.0))
        assert r.mask[32, 32, 32] and not r.mask[32, 52, 32]
        assert r.stats["kept_components"] == 1
```

- [ ] **Step 2: Ver que falla**

Run: `cd backend && .venv\Scripts\python -m pytest test_vascular_mask.py -q`
Expected: FAIL (módulo inexistente).

- [ ] **Step 3: Implementación**

```python
# backend/services/vascular_mask.py
"""De un volumen a una máscara de vasos: macizos, sin hueso, con sus sacos.

Medido en Case 3 (384³ 3DRA, umbral 1470):
  · umbral solo: 568 017 vóxeles, 9 924 componentes a media resolución, láminas
    del peñasco pegadas a la vasculatura, y vasos huecos cuando hay techo;
  · esta máscara: 149 208 vóxeles tubulares + 53 801 recuperados a 3 mm,
    1 componente, y la lesión confirmada conserva el 99 % de sus vóxeles.

Fases (cada una publica progreso):
  1 núcleo    M0 = vol ≥ lower, relleno 3D; el techo (si lo hay) se aplica
              DESPUÉS del relleno, así que un vaso cuyo centro lo supera sigue
              macizo. Antes el techo vaciaba los vasos más llenos.
  2 tubular   V = Frangi(1) máximo entre escalas; se MIDE core_vox =
              |M0 ∧ V ≥ p60(V | M0)| (la puerta no filtra: es la cifra de núcleo).
  3 semillas  componentes de M0 ∧ V ≥ p90 con ≥ 50 mm³: los troncos gruesos.
  4 crecer    lo conectado a una semilla dentro de M0 ∧ V ≥ p40 (histéresis).
  5 recuperar M0 a ≤ 3 mm geodésicos del tubo (pared que el crecimiento adelgazó,
              y los sacos, que no son tubos), vetando lo que es lámina.
  6 cerrar    cierre de 1 vóxel y relleno final.
"""
from __future__ import annotations

from dataclasses import dataclass, field
from typing import Callable

import numpy as np
from scipy import ndimage

from services.vesselness import objectness_max

@dataclass
class MaskParams:
    lower: float
    upper: float = 0.0
    gate_pctl: float = 60.0       # solo mide core_vox (la puerta no filtra)
    seed_pctl: float = 90.0
    grow_pctl: float = 40.0
    seed_min_mm3: float = 50.0
    reclaim_mm: float = 3.0
    plate_veto: bool = True
    closing_iter: int = 1

@dataclass
class MaskResult:
    mask: np.ndarray
    stats: dict = field(default_factory=dict)
    fallback: bool = False

def _say(on_progress: Callable[[str, float], None] | None, phase: str, pct: float) -> None:
    if on_progress:
        on_progress(phase, pct)

def build_vascular_mask(
    volume: np.ndarray,
    spacing: tuple[float, float, float],
    params: MaskParams,
    *,
    vesselness: np.ndarray | None = None,
    plateness: np.ndarray | None = None,
    on_progress: Callable[[str, float], None] | None = None,
) -> MaskResult:
    vox_mm3 = float(np.prod(spacing))
    stats: dict = {}

    # 1 · núcleo relleno, techo después
    _say(on_progress, "núcleo", 2)
    m0 = ndimage.binary_fill_holes(np.asarray(volume) >= params.lower)
    if params.upper > params.lower:
        m0 &= np.asarray(volume) <= params.upper
        m0 = ndimage.binary_fill_holes(m0)
    stats["m0_vox"] = int(m0.sum())
    if stats["m0_vox"] == 0:
        return MaskResult(m0, stats | {"seeds": 0, "final_vox": 0, "kept_fraction": 0.0}, fallback=True)

    # 2 · tubularidad
    if vesselness is None:
        vesselness = objectness_max(volume, spacing, dimension=1,
                                    on_progress=lambda i, n: _say(on_progress, f"tubularidad {i}/{n}", 5 + 40 * i / n))
    vin = vesselness[m0]
    t_gate = float(np.percentile(vin, params.gate_pctl))
    t_seed = float(np.percentile(vin, params.seed_pctl))
    t_grow = float(np.percentile(vin, params.grow_pctl))
    stats["thresholds"] = {"gate": t_gate, "seed": t_seed, "grow": t_grow}
    core = m0 & (vesselness >= t_gate)
    stats["core_vox"] = int(core.sum())

    # 3 · semillas: los troncos
    _say(on_progress, "semillas", 50)
    lab_s, _ = ndimage.label(m0 & (vesselness >= t_seed))
    sizes = np.bincount(lab_s.ravel()); sizes[0] = 0
    big = np.flatnonzero(sizes * vox_mm3 >= params.seed_min_mm3)
    stats["seeds"] = int(len(big))
    if len(big) == 0:
        stats.update(final_vox=int(m0.sum()), kept_fraction=1.0, grow_components=0,
                     kept_components=0, reclaimed_vox=0, vetoed_vox=0)
        return MaskResult(m0, stats, fallback=True)
    seed_mask = np.isin(lab_s, big)
    del lab_s

    # 4 · crecer por histéresis
    _say(on_progress, "crecimiento", 58)
    lab_g, n_g = ndimage.label(m0 & (vesselness >= t_grow))
    keep = np.unique(lab_g[seed_mask]); keep = keep[keep > 0]
    tube = np.isin(lab_g, keep)
    stats["grow_components"], stats["kept_components"] = int(n_g), int(len(keep))
    del lab_g

    # 5 · recuperar pared y sacos, vetando láminas
    reclaimed = np.zeros_like(tube)
    vetoed = 0
    if params.reclaim_mm > 0:
        _say(on_progress, "recuperación", 66)
        dist = ndimage.distance_transform_edt(~tube, sampling=spacing)
        near = m0 & (dist <= params.reclaim_mm) & ~tube
        del dist
        if params.plate_veto and near.any():
            if plateness is None:
                plateness = objectness_max(volume, spacing, dimension=2,
                                           on_progress=lambda i, n: _say(on_progress, f"laminaridad {i}/{n}", 66 + 20 * i / n))
            # Es lámina lo que puntúa más como lámina que como tubo.
            plate = plateness > vesselness
            vetoed = int((near & plate).sum())
            near &= ~plate
        lab_r, _ = ndimage.label(near | tube)
        keep = np.unique(lab_r[tube]); keep = keep[keep > 0]
        reclaimed = np.isin(lab_r, keep) & ~tube
        del lab_r
    stats["reclaimed_vox"], stats["vetoed_vox"] = int(reclaimed.sum()), vetoed

    # 6 · cerrar y rellenar
    _say(on_progress, "cierre", 90)
    final = tube | reclaimed
    if params.closing_iter > 0:
        final = ndimage.binary_closing(final, iterations=params.closing_iter) | final
    final = ndimage.binary_fill_holes(final)
    stats["final_vox"] = int(final.sum())
    stats["kept_fraction"] = float(final.sum() / max(1, m0.sum()))
    return MaskResult(final, stats, fallback=False)
```

- [ ] **Step 4: Ejecutar**

Run: `cd backend && .venv\Scripts\python -m pytest test_vascular_mask.py -v`
Expected: PASS. Si `test_una_lamina_en_contacto_no_vuelve_con_la_recuperacion` no baja del 15 %, ajusta el criterio de lámina a `plateness > 1.5 * vesselness` y anota en el informe el valor con el que pasa Y con el que el test del saco sigue pasando; si `test_una_rama_suelta_sin_semilla_se_descarta` falla porque el tubo fino sí genera semilla, baja su radio a 0,7 mm en el test.

- [ ] **Step 5: Commit**

```bash
git add backend/services/vascular_mask.py backend/test_vascular_mask.py
git commit -m "La máscara vascular: vasos macizos, hueso fuera por tubularidad y sacos recuperados a 3 mm"
```

---

### Task 4: Superficie estanca y decimación para detección

**Files:**
- Modify: `backend/services/segmentation.py` (añadir `mask_to_surface`, `decimate_to`, `surface_quality`)
- Create: `backend/test_surface.py`

**Interfaces:**
- Produces: `mask_to_surface(mask: np.ndarray, spacing, *, smooth_iters: int = 40, pass_band: float = 0.05, decimation: float = 0.6, fill_holes_mm: float = 4.0, min_island_mm3: float = 2.0, gauss_sigma_vox: float = 0.7, on_progress=None) -> vtk.vtkPolyData`.
- Produces: `decimate_to(poly: vtk.vtkPolyData, max_vertices: int) -> vtk.vtkPolyData` (devuelve el mismo objeto si ya cabe).
- Produces: `surface_quality(poly) -> dict` con `boundary_edges`, `components`, `aspect_ratio_median`, `n_vertices`, `n_triangles`.

- [ ] **Step 1: Tests que fallan**

```python
# backend/test_surface.py
"""Superficie estanca a partir de una máscara, y decimación acotada."""
from __future__ import annotations

import numpy as np
import vtk

from services.segmentation import decimate_to, mask_to_surface, surface_quality
from test_vesselness import SP, synthetic_tube

class TestEstanca:
    def test_un_tubo_da_una_superficie_sin_bordes_ni_islas(self):
        mask = synthetic_tube(shape=(64, 48, 48), radius_mm=2.0) > 0
        poly = mask_to_surface(mask, SP)
        q = surface_quality(poly)
        assert q["boundary_edges"] == 0
        assert q["components"] == 1
        assert q["aspect_ratio_median"] < 1.45
        assert q["n_vertices"] > 100

    def test_el_volumen_encerrado_se_parece_al_de_la_mascara(self):
        mask = synthetic_tube(shape=(64, 48, 48), radius_mm=2.0) > 0
        poly = mask_to_surface(mask, SP)
        mp = vtk.vtkMassProperties(); mp.SetInputData(poly); mp.Update()
        esperado = float(mask.sum()) * float(np.prod(SP))
        assert abs(mp.GetVolume() - esperado) / esperado < 0.12

    def test_un_agujero_pequeno_en_la_pared_se_cierra(self):
        mask = synthetic_tube(shape=(64, 48, 48), radius_mm=2.0) > 0
        mask[30:33, 24, 26:29] = False          # un pinchazo de ~1 mm en la pared
        poly = mask_to_surface(mask, SP)
        assert surface_quality(poly)["boundary_edges"] == 0

    def test_las_islas_diminutas_desaparecen(self):
        mask = synthetic_tube(shape=(64, 48, 48), radius_mm=2.0) > 0
        mask[5, 5, 5] = True                    # una mota de 0,125 mm³
        poly = mask_to_surface(mask, SP)
        assert surface_quality(poly)["components"] == 1

    def test_informa_del_progreso(self):
        mask = synthetic_tube(shape=(32, 32, 32), radius_mm=2.0) > 0
        fases: list[str] = []
        mask_to_surface(mask, SP, on_progress=lambda f, p: fases.append(f))
        assert fases[0] == "superficie" and "decimación" in fases

class TestDecimacion:
    def test_reduce_hasta_el_tope_y_no_toca_lo_que_ya_cabe(self):
        mask = synthetic_tube(shape=(96, 64, 64), radius_mm=3.0) > 0
        poly = mask_to_surface(mask, SP, decimation=0.0)
        n = poly.GetNumberOfPoints()
        small = decimate_to(poly, max_vertices=n // 3)
        assert small.GetNumberOfPoints() <= n // 3 * 1.05
        assert decimate_to(poly, max_vertices=n + 1) is poly
```

- [ ] **Step 2: Ver que falla**

Run: `cd backend && .venv\Scripts\python -m pytest test_surface.py -q`
Expected: FAIL (`ImportError`).

- [ ] **Step 3: Implementación** (añade al final de `services/segmentation.py`, tras `write_vtp`/`read_vtp`)

```python
# ── Superficie estanca a partir de una máscara ─────────────────────────────── #
#
# La malla antigua salía de marching cubes sobre un binario: escalones, 67
# aristas de borde y triángulos alargados. Aquí la máscara se suaviza a float
# antes (superficie sub-vóxel), se cierra lo que quede abierto y se decima con
# normales. Criterio del diseño: 0 aristas de borde, aspecto mediano < 1,45.

def mask_to_surface(
    mask: np.ndarray,
    spacing: tuple[float, float, float],
    *,
    smooth_iters: int = 40,
    pass_band: float = 0.05,
    decimation: float = 0.6,
    fill_holes_mm: float = 4.0,
    min_island_mm3: float = 2.0,
    gauss_sigma_vox: float = 0.7,
    on_progress=None,
) -> vtk.vtkPolyData:
    from scipy import ndimage

    def say(phase: str, pct: float) -> None:
        if on_progress:
            on_progress(phase, pct)

    say("superficie", 0)
    field = ndimage.gaussian_filter(mask.astype(np.float32), gauss_sigma_vox)
    img = SegmentationPipeline._to_vtk_image(field, spacing)
    mc = vtk.vtkMarchingCubes()
    mc.SetInputData(img); mc.SetValue(0, 0.5)
    mc.ComputeNormalsOff(); mc.ComputeGradientsOff(); mc.Update()
    if mc.GetOutput().GetNumberOfPolys() == 0:
        raise ValueError("La máscara no contiene ninguna superficie.")

    say("suavizado", 25)
    prev = mc.GetOutputPort()
    if smooth_iters > 0:
        sm = vtk.vtkWindowedSincPolyDataFilter()
        sm.SetInputConnection(prev); sm.SetNumberOfIterations(smooth_iters); sm.SetPassBand(pass_band)
        sm.BoundarySmoothingOff(); sm.FeatureEdgeSmoothingOff(); sm.NonManifoldSmoothingOn(); sm.NormalizeCoordinatesOn()
        sm.Update(); prev = sm.GetOutputPort()

    if fill_holes_mm > 0:
        fh = vtk.vtkFillHolesFilter()
        fh.SetInputConnection(prev); fh.SetHoleSize(fill_holes_mm); fh.Update(); prev = fh.GetOutputPort()

    say("decimación", 55)
    if decimation > 0:
        dec = vtk.vtkQuadricDecimation()
        dec.SetInputConnection(prev); dec.SetTargetReduction(decimation); dec.Update(); prev = dec.GetOutputPort()

    say("normales", 75)
    nrm = vtk.vtkPolyDataNormals()
    nrm.SetInputConnection(prev); nrm.ComputePointNormalsOn(); nrm.ComputeCellNormalsOff()
    nrm.SplittingOff(); nrm.SetFeatureAngle(60.0); nrm.ConsistencyOn(); nrm.AutoOrientNormalsOn(); nrm.Update()
    poly = nrm.GetOutput()

    say("islas", 90)
    if min_island_mm3 > 0:
        poly = _drop_small_islands(poly, min_island_mm3)
    say("superficie lista", 100)
    return poly

def _drop_small_islands(poly: vtk.vtkPolyData, min_mm3: float) -> vtk.vtkPolyData:
    """Quita las piezas conexas con menos de `min_mm3` de volumen encerrado."""
    cf = vtk.vtkPolyDataConnectivityFilter()
    cf.SetInputData(poly); cf.SetExtractionModeToAllRegions(); cf.ColorRegionsOn(); cf.Update()
    n = cf.GetNumberOfExtractedRegions()
    if n <= 1:
        return poly
    keep = vtk.vtkPolyDataConnectivityFilter()
    keep.SetInputData(poly); keep.SetExtractionModeToSpecifiedRegions()
    kept = 0
    for r in range(n):
        one = vtk.vtkPolyDataConnectivityFilter()
        one.SetInputData(poly); one.SetExtractionModeToSpecifiedRegions(); one.AddSpecifiedRegion(r); one.Update()
        tri = vtk.vtkTriangleFilter(); tri.SetInputConnection(one.GetOutputPort()); tri.Update()
        mp = vtk.vtkMassProperties(); mp.SetInputConnection(tri.GetOutputPort()); mp.Update()
        if abs(mp.GetVolume()) >= min_mm3:
            keep.AddSpecifiedRegion(r); kept += 1
    if kept == 0:
        return poly
    keep.Update()
    cl = vtk.vtkCleanPolyData(); cl.SetInputConnection(keep.GetOutputPort()); cl.Update()
    return cl.GetOutput()

def decimate_to(poly: vtk.vtkPolyData, max_vertices: int) -> vtk.vtkPolyData:
    """La malla con como mucho `max_vertices` puntos, o la misma si ya cabe.

    La detección desactiva sus canales de calibre por encima de 40 000 vértices
    (medido: 52 s en 79 000). Decimar EN MEMORIA para detectar deja la malla
    completa en disco para medir.
    """
    n = poly.GetNumberOfPoints()
    if n <= max_vertices:
        return poly
    dec = vtk.vtkQuadricDecimation()
    dec.SetInputData(poly); dec.SetTargetReduction(1.0 - max_vertices / float(n)); dec.Update()
    nrm = vtk.vtkPolyDataNormals()
    nrm.SetInputConnection(dec.GetOutputPort()); nrm.SplittingOff(); nrm.ConsistencyOn(); nrm.AutoOrientNormalsOn(); nrm.Update()
    return nrm.GetOutput()

def surface_quality(poly: vtk.vtkPolyData) -> dict:
    fe = vtk.vtkFeatureEdges()
    fe.SetInputData(poly); fe.BoundaryEdgesOn(); fe.FeatureEdgesOff(); fe.NonManifoldEdgesOff(); fe.ManifoldEdgesOff(); fe.Update()
    cf = vtk.vtkPolyDataConnectivityFilter()
    cf.SetInputData(poly); cf.SetExtractionModeToAllRegions(); cf.Update()
    q = vtk.vtkMeshQuality()
    q.SetInputData(poly); q.SetTriangleQualityMeasureToAspectRatio(); q.Update()
    ar = ns.vtk_to_numpy(q.GetOutput().GetCellData().GetArray("Quality"))
    return {
        "boundary_edges": int(fe.GetOutput().GetNumberOfLines()),
        "components": int(cf.GetNumberOfExtractedRegions()),
        "aspect_ratio_median": float(np.median(ar)) if ar.size else 0.0,
        "n_vertices": int(poly.GetNumberOfPoints()),
        "n_triangles": int(poly.GetNumberOfPolys()),
    }
```

- [ ] **Step 4: Ejecutar**

Run: `cd backend && .venv\Scripts\python -m pytest test_surface.py -v`
Expected: PASS. Si `test_un_agujero_pequeno_en_la_pared_se_cierra` deja aristas, comprueba que el pinchazo es menor que `fill_holes_mm` (perímetro ≈ 3 mm) y que `vtkFillHolesFilter` recibe triángulos (añade un `vtkTriangleFilter` antes si el suavizado devuelve polígonos); anota en el informe.

- [ ] **Step 5: Commit**

```bash
git add backend/services/segmentation.py backend/test_surface.py
git commit -m "La superficie sale de la máscara suavizada, sin huecos ni islas, y se puede decimar para detectar"
```

---

### Task 5: El método tubular en el router de segmentación, con fases y guardas

**Files:**
- Modify: `backend/models/segmentation.py` (`SegmentRequest.method`, `SegmentRequest.reclaim_mm`, `SegmentRequest.half_resolution`; `SegmentResult.method`, `.kept_fraction`, `.reclaimed_mm3`, `.vetoed_mm3`, `.boundary_edges`, `.components`, `.seeds`, `.fallback_note`, `.phase_seconds`)
- Modify: `backend/routers/segment.py` (`_run_segmentation_sync`)
- Create: `backend/test_segment_tubular.py`

**Interfaces:**
- Consumes: `progress` (Task 1), `objectness_max`/`auto_gamma` (Task 2), `MaskParams`/`build_vascular_mask` (Task 3), `mask_to_surface`/`surface_quality` (Task 4).
- Produces: `POST /api/segment` acepta `method: "tubular" | "threshold"` (por defecto `"tubular"`), `reclaim_mm: float = 3.0` (0–5), `half_resolution: bool = False` (sustituye a `full_resolution`, que se mantiene aceptado y con el significado inverso mientras el frontend migra: si llega `full_resolution`, `half_resolution = not full_resolution`). `SegmentResult` añade `method`, `reclaimed_mm3`, `vetoed_mm3`, `boundary_edges`, `components`, `seeds`, `fallback_note: str`, `phase_seconds: dict[str, float]`; `kept_fraction` pasa a ser final/M0 en el método tubular.
- Fases publicadas (en este orden, con estos nombres): `carga`, `núcleo`, `tubularidad i/n`, `semillas`, `crecimiento`, `recuperación`, `laminaridad i/n`, `cierre`, `superficie`, `suavizado`, `decimación`, `normales`, `islas`, `guardado`.

- [ ] **Step 1: Tests que fallan**

```python
# backend/test_segment_tubular.py
"""El método tubular por la API: fases, guardas y resultado."""
from __future__ import annotations

import time
import threading

import numpy as np
from fastapi.testclient import TestClient

from main import app
from services import progress
from services.segmentation import read_vtp, surface_quality
from services.sessions import create_session, session_subdir
from test_volume_chunks import _write_classic_ct_series

client = TestClient(app, raise_server_exceptions=True)

def _tube_series(sid: str, nz=40, size=48, radius_mm=3.0, core=0.0):
    """Un tubo brillante a lo largo de z en una serie clásica de `nz` cortes."""
    z, y, x = np.mgrid[0:nz, 0:size, 0:size].astype(np.float32)
    d2 = (y - size / 2) ** 2 + (x - size / 2) ** 2         # spacing 1 mm en el helper
    vol = np.where(d2 <= radius_mm ** 2, 800.0, 0.0)
    if core:
        vol = np.where(d2 <= (radius_mm / 3) ** 2, core, vol)
    _write_classic_ct_series(sid, nz=nz, size=size, values=vol.astype(np.int16))

def _segment(sid: str, **over):
    body = {"session_id": sid, "series_id": "", "lower": 300.0, "upper": 0.0,
            "smoothing": 3, "cleanup": 0, "main_tree_only": False, "method": "tubular"}
    body.update(over)
    return client.post("/api/segment", json=body)

class TestTubular:
    def test_devuelve_una_malla_estanca_y_sus_cifras(self):
        sid = create_session(); _tube_series(sid)
        r = _segment(sid)
        assert r.status_code == 200, r.text
        j = r.json()
        assert j["method"] == "tubular"
        assert j["boundary_edges"] == 0 and j["components"] == 1
        assert j["seeds"] >= 1 and j["fallback_note"] == ""
        assert set(j["phase_seconds"]) >= {"tubularidad", "superficie", "guardado"}
        poly = read_vtp(session_subdir(sid, "meshes") / "vessel_tree.vtp")
        assert surface_quality(poly)["boundary_edges"] == 0

    def test_el_techo_ya_no_vacia_el_vaso(self):
        sid = create_session(); _tube_series(sid, core=3000.0)
        j = _segment(sid, upper=2000.0).json()
        assert j["components"] == 1 and j["boundary_edges"] == 0
        # Con el método antiguo el mismo techo dejaba una cáscara doble.
        j2 = _segment(sid, upper=2000.0, method="threshold").json()
        assert j2["method"] == "threshold"

    def test_sin_semillas_lo_dice_y_no_falla(self):
        sid = create_session(); _tube_series(sid, radius_mm=0.8)
        j = _segment(sid).json()
        assert "semilla" in j["fallback_note"].lower()

    def test_el_progreso_avanza_por_fases_durante_la_segmentacion(self):
        sid = create_session(); _tube_series(sid, nz=64, size=64)
        seen: list[str] = []
        stop = threading.Event()
        def watch():
            while not stop.is_set():
                p = progress.get(sid)
                if p and p["phase"] and (not seen or seen[-1] != p["phase"]):
                    seen.append(p["phase"])
                time.sleep(0.01)
        t = threading.Thread(target=watch); t.start()
        try:
            assert _segment(sid).status_code == 200
        finally:
            stop.set(); t.join()
        assert "superficie" in seen and any(s.startswith("tubularidad") for s in seen)
        assert progress.get(sid)["running"] is False and progress.get(sid)["ok"] is True

    def test_media_resolucion_se_fuerza_por_encima_del_tope(self, monkeypatch):
        from routers import segment as seg
        monkeypatch.setattr(seg, "_TUBULAR_MAX_VOXELS", 1000)
        sid = create_session(); _tube_series(sid, nz=40, size=48)      # 92 160 vóxeles
        j = _segment(sid).json()
        assert j["downsample_factor"] == 2
        assert "media resolución" in j["fallback_note"].lower()

    def test_full_resolution_sigue_aceptandose_con_el_significado_inverso(self):
        sid = create_session(); _tube_series(sid)
        j = _segment(sid, full_resolution=False).json()
        assert j["downsample_factor"] == 2
```

- [ ] **Step 2: Ver que falla**

Run: `cd backend && .venv\Scripts\python -m pytest test_segment_tubular.py -q`
Expected: FAIL (422 por `method` desconocido, o `KeyError: 'method'`). Si `_write_classic_ct_series` no acepta `values`, amplíala en `test_volume_chunks.py` con un parámetro opcional `values: np.ndarray | None` (int16, forma `(nz, size, size)`) que sustituye al cubo brillante; los tests existentes no cambian.

- [ ] **Step 3: Modelos**

En `backend/models/segmentation.py`, `SegmentRequest` añade:

```python
    method: Literal["tubular", "threshold"] = Field(
        "tubular",
        description=(
            "«tubular»: máscara por tubularidad (Frangi) con núcleo relleno, "
            "hueso vetado y sacos recuperados; «threshold»: el umbral clásico."
        ),
    )
    reclaim_mm: float = Field(3.0, ge=0.0, le=5.0, description="Radio de recuperación de pared y sacos (mm), método tubular")
    half_resolution: bool = Field(
        False,
        description="Segmentar con el eje mayor a 256 en vez de a resolución nativa (más rápido, vasos finos rotos).",
    )
```

y `full_resolution` pasa a `bool | None = Field(None, description="Obsoleto: inverso de half_resolution")`. `SegmentResult` añade:

```python
    method: str = "threshold"
    reclaimed_mm3: float = 0.0
    vetoed_mm3: float = 0.0
    boundary_edges: int = 0
    components: int = 0
    seeds: int = 0
    fallback_note: str = ""
    phase_seconds: dict[str, float] = Field(default_factory=dict)
```

(importa `Literal` de `typing`).

- [ ] **Step 4: Router**

En `backend/routers/segment.py`:

```python
_TUBULAR_MAX_VOXELS = 90_000_000   # por encima, media resolución forzada (1 vCPU / 2 GB)
```

En `segment()`: resuelve `half = req.half_resolution if req.full_resolution is None else (not req.full_resolution)` y pasa `method=req.method, reclaim_mm=req.reclaim_mm, half_resolution=half` a `_run_segmentation_sync`; elimina el parámetro `full_resolution` de la firma síncrona. Envuelve la llamada al executor con `progress.start(req.session_id)` antes y `progress.finish(req.session_id, ok=True)` / `progress.finish(req.session_id, ok=False, message=str(exc))` en cada rama de error.

En `_run_segmentation_sync`, tras cargar el DICOM y calcular `strategy`/`vf` (déjalo como está), sustituye el bloque «Downsample very large volumes» + «Run marching cubes» por:

```python
    phase_seconds: dict[str, float] = {}
    fallback_note = ""
    say = lambda phase, pct: progress.update(session_id, phase, pct)   # noqa: E731

    def timed(name, fn):
        t = time.perf_counter()
        out = fn()
        phase_seconds[name] = round(time.perf_counter() - t, 2)
        return out

    n_voxels = int(np.prod(dcm.volume.shape))
    if method == "tubular" and not half_resolution and n_voxels > _TUBULAR_MAX_VOXELS:
        half_resolution = True
        fallback_note = (f"Volumen de {n_voxels / 1e6:.0f} millones de vóxeles: se segmenta a "
                         f"media resolución para no agotar la memoria del servidor.")
    if half_resolution:
        seg_volume, seg_spacing, ds_factor = _maybe_downsample(dcm.volume, dcm.spacing)
    else:
        seg_volume, seg_spacing, ds_factor = np.ascontiguousarray(dcm.volume, dtype=np.float32), tuple(dcm.spacing), 1

    if method == "tubular":
        from services.vascular_mask import MaskParams, build_vascular_mask
        from services.segmentation import mask_to_surface, surface_quality
        say("núcleo", 2)
        params = MaskParams(lower=lower, upper=upper if upper > lower else 0.0, reclaim_mm=reclaim_mm)
        mr = timed("máscara", lambda: build_vascular_mask(seg_volume, seg_spacing, params, on_progress=say))
        if mr.fallback:
            fallback_note = (fallback_note + " " if fallback_note else "") + (
                "No se encontró ninguna semilla vascular ≥ 50 mm³ con este umbral: se usó la máscara de umbral "
                "rellena, sin filtrar por tubularidad. Baja el umbral inferior si falta contraste.")
        poly = timed("superficie", lambda: mask_to_surface(
            mr.mask, seg_spacing, smooth_iters=smooth_iters,
            on_progress=lambda f, p: say(f, 90 + p / 10)))
        vox_mm3 = float(np.prod(seg_spacing))
        q = surface_quality(poly)
        seg_result = SegmentationResult(
            poly_data=poly, n_vertices=q["n_vertices"], n_triangles=q["n_triangles"],
            threshold_hu=lower, reduction_pct=60.0, n_fragments_removed=0,
            kept_fraction=mr.stats.get("kept_fraction", 1.0), largest_removed_mm3=0.0)
        extra = dict(method="tubular", reclaimed_mm3=round(mr.stats.get("reclaimed_vox", 0) * vox_mm3, 1),
                     vetoed_mm3=round(mr.stats.get("vetoed_vox", 0) * vox_mm3, 1),
                     boundary_edges=q["boundary_edges"], components=q["components"],
                     seeds=int(mr.stats.get("seeds", 0)))
        # Separa el tiempo de tubularidad del de máscara para la interfaz.
        phase_seconds["tubularidad"] = phase_seconds.get("máscara", 0.0)
    else:
        say("marching cubes", 20)
        seg_result = timed("marching cubes", lambda: pipeline.run(seg_volume, seg_spacing))
        extra = dict(method="threshold")
```

El resto (árbol principal, `write_vtp`, `scan_and_freeze`, limpieza de detección, estado) queda igual, envuelto en `timed("guardado", ...)` para la escritura; `seg.method` se escribe en el estado (`write_state(session_id, "seg.method", method)`). El `SegmentResult` devuelto añade `**extra`, `fallback_note=fallback_note`, `phase_seconds=phase_seconds`. `main_tree_only` con el método tubular sigue funcionando (la máscara ya es un componente, así que normalmente no quita nada).

- [ ] **Step 5: Ejecutar**

Run: `cd backend && .venv\Scripts\python -m pytest test_segment_tubular.py test_segment_preview.py test_comparar_techo.py -q`
Expected: PASS. `test_comparar_techo.py` usa el pipeline antiguo por `comparar_techo`; no debe cambiar.

- [ ] **Step 6: Commit**

```bash
git add backend/models/segmentation.py backend/routers/segment.py backend/test_segment_tubular.py backend/test_volume_chunks.py
git commit -m "Segmentar por tubularidad es el método por defecto, con fases de progreso y guarda de memoria"
```

---

### Task 6: Detección sobre la malla decimada y reintento del plano de cuello

**Files:**
- Modify: `backend/routers/detect.py` (`_run_detection_sync`, `_run_morphometry_sync`)
- Modify: `backend/test_detector_case3.py` (nuevo test), `backend/test_neck_plane_feedback.py` (nuevo test)

**Interfaces:**
- Consumes: `decimate_to` (Task 4), `isolate_closed_sac`/`isolate_sac_volumetric` existentes.
- Produces: `_DETECT_MAX_VERTS = 40_000`; la detección corre sobre `decimate_to(poly, _DETECT_MAX_VERTS)` y los parches de candidato se recortan de la malla COMPLETA (`hit_patch(poly_full, hit)`), así que el `.vtp` de cada candidato sigue siendo a resolución completa. `_run_morphometry_sync` prueba desplazamientos `(0, +1, −1, +2, −2)` mm del origen a lo largo de la normal antes de rendirse, y guarda en `morpho.neck_shift_mm` el que usó.

- [ ] **Step 1: Tests que fallan**

Añade a `backend/test_detector_case3.py` (usa el fixture `malla` existente del archivo):

```python
class TestDetectarSobreLaMallaCompleta:
    def test_una_malla_de_mas_de_40k_vertices_no_pierde_los_canales_de_calibre(self, malla):
        # Se sube la malla artificialmente por encima del tope subdividiéndola.
        import vtk
        from routers.detect import _detect_hits
        sub = vtk.vtkLinearSubdivisionFilter(); sub.SetInputData(malla); sub.SetNumberOfSubdivisions(2); sub.Update()
        grande = sub.GetOutput()
        assert grande.GetNumberOfPoints() > 40_000
        hits = _detect_hits(grande, "XA")
        assert any(("calibre" in h.channels) or ("cociente" in h.channels) for h in hits)
```

Añade a `backend/test_neck_plane_feedback.py`:

```python
class TestReintentoDelPlano:
    def test_un_origen_un_milimetro_fuera_del_cuello_se_corrige_solo(self, sesion_con_saco):
        # `sesion_con_saco` es el fixture del archivo que deja un tubo con un saco y
        # un plano que SÍ aísla; aquí se desplaza el origen 1 mm hacia el vaso.
        sid, origin, normal = sesion_con_saco
        malo = [origin[i] - 1.0 * normal[i] for i in range(3)]
        r = client.post(f"/api/morphometry/{sid}/neck-plane",
                        json={"origin": {"x": malo[0], "y": malo[1], "z": malo[2]}, "normal": list(normal)})
        assert r.status_code == 200, r.text
        from services.sessions import read_state
        assert abs(float(read_state(sid, "morpho.neck_shift_mm", "0"))) == 1.0
```

Si `test_neck_plane_feedback.py` no tiene un fixture equivalente a `sesion_con_saco`, créalo en ese archivo a partir de lo que ya usa para probar el plano de cuello (un tubo con una esfera pegada segmentado por `/api/segment` con `method="threshold"`), y dilo en el informe.

- [ ] **Step 2: Ver que fallan**

Run: `cd backend && .venv\Scripts\python -m pytest test_detector_case3.py test_neck_plane_feedback.py -q`
Expected: FAIL (`_detect_hits` no existe; el reintento no existe).

- [ ] **Step 3: Implementación**

En `routers/detect.py` extrae de `_run_detection_sync` la parte que construye el detector y llama a `consensus` a:

```python
_DETECT_MAX_VERTS = 40_000

def _detect_hits(poly: "vtk.vtkPolyData", modality: str):
    """Los candidatos, calculados sobre una copia decimada si la malla es grande.

    La malla completa (124 000 vértices en Case 3 a resolución nativa) hace que
    `consensus` apague sus canales de calibre por encima de 40 000; decimarla
    solo para buscar devuelve esos canales, y los parches se recortan luego de
    la malla completa.
    """
    from services.segmentation import decimate_to
    detector = _detector_for_modality(modality)
    small = decimate_to(poly, _DETECT_MAX_VERTS)
    return consensus(small, detector, top=_MAX_CANDIDATES)
```

y en `_run_detection_sync` usa `hits = _detect_hits(poly, modality)` manteniendo `hit_patch(poly, hit)` sobre la malla completa; el `det_result = detector.detect(...)` que alimenta los diagnósticos de la respuesta corre también sobre la copia decimada (devuélvelo desde `_detect_hits` como segundo valor si el router lo necesita). Registra en el log el número de vértices antes y después.

En `_run_morphometry_sync`, envuelve el bloque que aísla el saco (volumétrico + superficie) en un bucle:

```python
        shifts = (0.0, 1.0, -1.0, 2.0, -2.0)
        last_error: Exception | None = None
        for shift in shifts:
            o = tuple(origin[i] + shift * normal[i] for i in range(3))
            try:
                sac_mesh, neck_diam = _isolate_sac(session_id, vtp_path, o, normal, seed, bound_r, crop_half)
            except ValueError as exc:
                last_error = exc
                continue
            if sac_mesh is not None and sac_mesh.GetNumberOfPoints() >= 50 and neck_diam > 0.3:
                origin = o
                write_state(session_id, "morpho.neck_shift_mm", str(shift))
                if shift:
                    logger.info("Neck plane shifted %.0f mm along the normal to isolate the sac", shift)
                break
        else:
            raise ValueError(
                "No se aísla un saco válido con este plano ni desplazándolo ±2 mm. "
                "Verifica que el punto de cuello esté sobre el cuello y el ápice sobre la cúpula del domo."
            ) from last_error
```

donde `_isolate_sac(...)` es el código actual (volumétrico con fallback a superficie) movido a una función que devuelve `(sac_mesh, neck_diam)` o lanza `ValueError`.

- [ ] **Step 4: Ejecutar**

Run: `cd backend && .venv\Scripts\python -m pytest test_detector_case3.py test_neck_plane_feedback.py test_morphometry_sac.py test_consensus_and_plane.py -q`
Expected: PASS (los tests del Case 3 que fijan la posición de la lesión deben seguir pasando: la decimación se hace sobre una copia).

- [ ] **Step 5: Commit**

```bash
git add backend/routers/detect.py backend/test_detector_case3.py backend/test_neck_plane_feedback.py
git commit -m "La detección busca sobre una copia decimada y el plano de cuello se reintenta a ±2 mm"
```

---

### Task 7: La meta del volumen deja de guardar copias obsoletas tras preprocesar

**Files:**
- Modify: `backend/routers/preprocess.py`
- Modify: `backend/test_preprocess.py`

**Interfaces:**
- Produces: tras `POST /api/preprocess/{sid}`, `_volume_meta.json` contiene `full_stride` e `intensity_range` recalculados sobre el volumen nuevo, y NO contiene `cache_key` ni `orientation_manual` (que son por llamada).

- [ ] **Step 1: Test que falla**

Añade a `backend/test_preprocess.py` (sigue el patrón de sesión sintética que ya usa el archivo):

```python
def test_preprocesar_recalcula_el_rango_y_no_persiste_claves_por_llamada(session_with_ct_volume):
    sid = session_with_ct_volume
    from services.mpr import _cache_paths
    import json
    r = client.post(f"/api/preprocess/{sid}", json={"clip_hu": True, "resample_isotropic": False, "smooth": False})
    assert r.status_code == 200, r.text
    meta = json.loads(_cache_paths(sid)[1].read_text())
    assert "cache_key" not in meta and "orientation_manual" not in meta
    assert meta["intensity_range"][1] <= 3000.0          # recortado a HU_MAX
    assert meta["full_stride"] == 1
```

Si el archivo no tiene un fixture `session_with_ct_volume`, créalo con un volumen CT sintético cuya intensidad llegue a 5000 (para que el recorte a 3000 sea observable) escribiendo `_volume.npy` y `_volume_meta.json` con `modality: "CT"`.

- [ ] **Step 2: Ver que falla** — `pytest test_preprocess.py -q -k recalcula` → FAIL.

- [ ] **Step 3: Implementación**

En `routers/preprocess.py::_run`, sustituye la construcción de `new_meta` por:

```python
    from services.mpr import _full_stride, _intensity_range, new_volume_id
    new_meta = {k: v for k, v in meta.items() if k not in ("cache_key", "orientation_manual")}
    new_meta["shape"] = [int(x) for x in new_vol.shape]
    new_meta["spacing"] = [float(s) for s in new_spacing]
    new_meta["intensity_range"] = _intensity_range(new_vol)
    new_meta["full_stride"] = _full_stride(new_meta["shape"])
    new_meta["volume_id"] = new_volume_id()
```

- [ ] **Step 4: Ejecutar** — `pytest test_preprocess.py test_volume_chunks.py -q` → PASS.

- [ ] **Step 5: Commit**

```bash
git add backend/routers/preprocess.py backend/test_preprocess.py
git commit -m "Preprocesar recalcula el rango de intensidad y no guarda claves que son por llamada"
```

---
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

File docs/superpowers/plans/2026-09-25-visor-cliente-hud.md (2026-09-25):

# Visor 2D/3D en el cliente + estética HUD — plan de implementación

> **For agentic workers:** REQUIRED SUB-SKILL: Use superpowers:subagent-driven-development (recommended) or superpowers:executing-plans to implement this plan task-by-task. Steps use checkbox (`- [ ]`) syntax for tracking.

**Goal:** Que los cortes, el oblicuo y un MIP progresivo se rendericen en el navegador desde una copia del volumen, en una distribución 1+3+MIP sincronizada por un punto común, con maniquí de orientación y una superposición estilo HUD de caza.

**Architecture:** El backend sirve el volumen por bloques `int16` gzip (más el `uint8` grueso ya existente) y añade orientación del paciente a la meta; el frontend guarda una copia en memoria y en la Cache API, la envuelve en un único `vtkImageData` y lo renderiza con `vtkImageMapper` (planos), `vtkImageResliceMapper` (oblicuo) y `vtkVolumeMapper` en MIP con planos de recorte (MIP progresivo). Un `focusPoint` en el store mueve crosshair y cámaras. Toda la superposición se hace con componentes HUD en React sobre el canvas.

**Tech Stack:** FastAPI + NumPy (backend), React 19 + TypeScript + vtk.js 36.2.1 (frontend), vitest + Testing Library, pytest.

**Spec:** `docs/superpowers/specs/2026-09-25-visor-segmentacion-clip-design.md` (secciones 3 y 6 bis).

## Global Constraints

- Backend en Lightsail 1 vCPU / 2 GB: ninguna ruta nueva carga el volumen entero en memoria; se lee del memmap `_volume.npy` por lonchas.
- Bloques `full` de **32 cortes** en z, `int16` little-endian, gzip. Volúmenes de más de **150 M vóxeles** se sirven con `stride 2` en el plano (cabecera `X-Level-Stride: 2`).
- El volumen se cachea en el navegador con clave `sid + cache_key` (mtime del `.npy`).
- Color de acento HUD `--hud: #8CFF9E`; ámbar `#FFC857`; contraste ≥ 4,5:1 sobre negro; el color nunca es el único canal de un aviso.
- Tipografía monoespaciada (`--font-mono`, JetBrains Mono) para toda lectura de instrumento; rótulos en mayúsculas con `letter-spacing: 0.08em`.
- Nada de scanlines, ruido ni parpadeo sobre el área de la imagen.
- Orientación de pantalla de los cortes idéntica a los PNG actuales: axial fila 0 arriba y x a la derecha; coronal y sagital con z máximo arriba.
- Textos de interfaz en español, como el resto de la app. Mensajes de commit en español, como el historial.
- `tsc -b`, `vitest run` y `pytest` en verde en cada commit.

## Review Focus

1. Volumen `full` que no cabe (TC 512×512×1030, 270 M vóxeles): debe servirse con stride 2 y el visor debe decir «resolución reducida», nunca intentar 540 MB. → test en Task 2 (`test_full_chunk_uses_stride_for_large_volume`).
2. Sesión cambiada a mitad de descarga: los bloques de la sesión anterior no deben escribirse en el buffer de la nueva. → test en Task 4 (`aborts previous download when session changes`).
3. Volumen sin etiquetas de orientación (3DRA de Case 3): etiquetas entre corchetes y maniquí en gris; nunca etiquetas «seguras» inventadas. → test en Task 3 (`labels are bracketed when orientation is assumed`).
4. Valores fuera de `int16` (XA en crudo puede superar 32 767): recorte, no desbordamiento con envoltura. → test en Task 2 (`test_full_chunk_clamps_to_int16`).
5. Doble clic para maximizar el panel que ya es el principal: no debe romper la distribución ni duplicar paneles. → test en Task 8 (`maximizing the main pane is a no-op`).
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

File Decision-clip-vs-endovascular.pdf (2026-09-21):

PROSPECTIVE · Revisión: decisión clip vs endovascular · documento de trabajo, no es consejo clínico | 1

PROSPECTIVE · Documento de revisión

# Decisión clip quirúrgico frente a tratamiento endovascular

En qué se basa el motor de la aplicación, qué fuentes cita, y qué dice la evidencia publicada a septiembre de 2026.

Qué es y qué no es este documento. Es una revisión de literatura y una auditoría del código que ya está escrito. No es consejo clínico, no lo firma un profesional sanitario y no sustituye a la sesión multidisciplinar, que es precisamente lo que todas las guías consultadas recomiendan como mecanismo de decisión. Las cifras del apartado 1 están leídas del código fuente; las del apartado 2, de las fuentes citadas al final. Donde la aplicación y la literatura no coinciden, el apartado 3 lo dice sin suavizarlo.

# 1. Qué hace hoy Prospective

El motor vive en backend/services/treatment.py. Es un sumatorio de puntos enteros: cada factor añade puntos a «clip» o a «endo», se restan, y el signo y la magnitud del saldo deciden el veredicto y la confianza. No hay probabilidades, no hay regresión y no hay ajuste a ninguna cohorte: son pesos fijos escritos a mano.
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

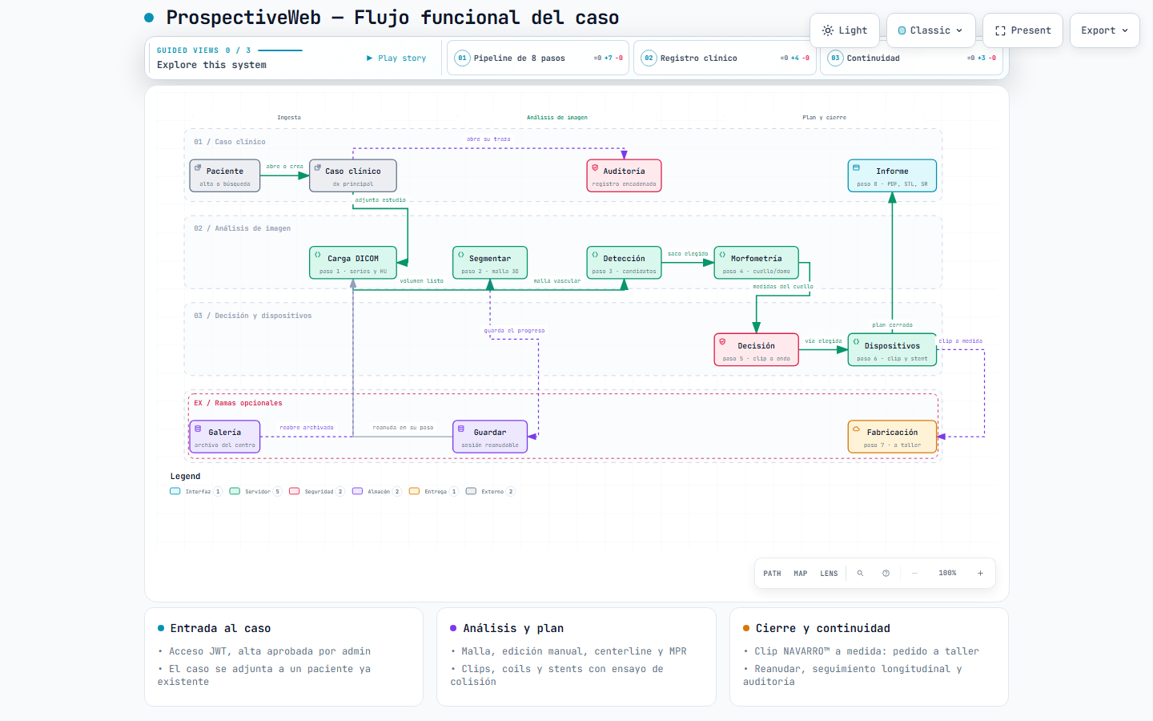
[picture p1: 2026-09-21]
docs/diagramas/prospectiveweb-flujo.visual-check.1440x900.light.png

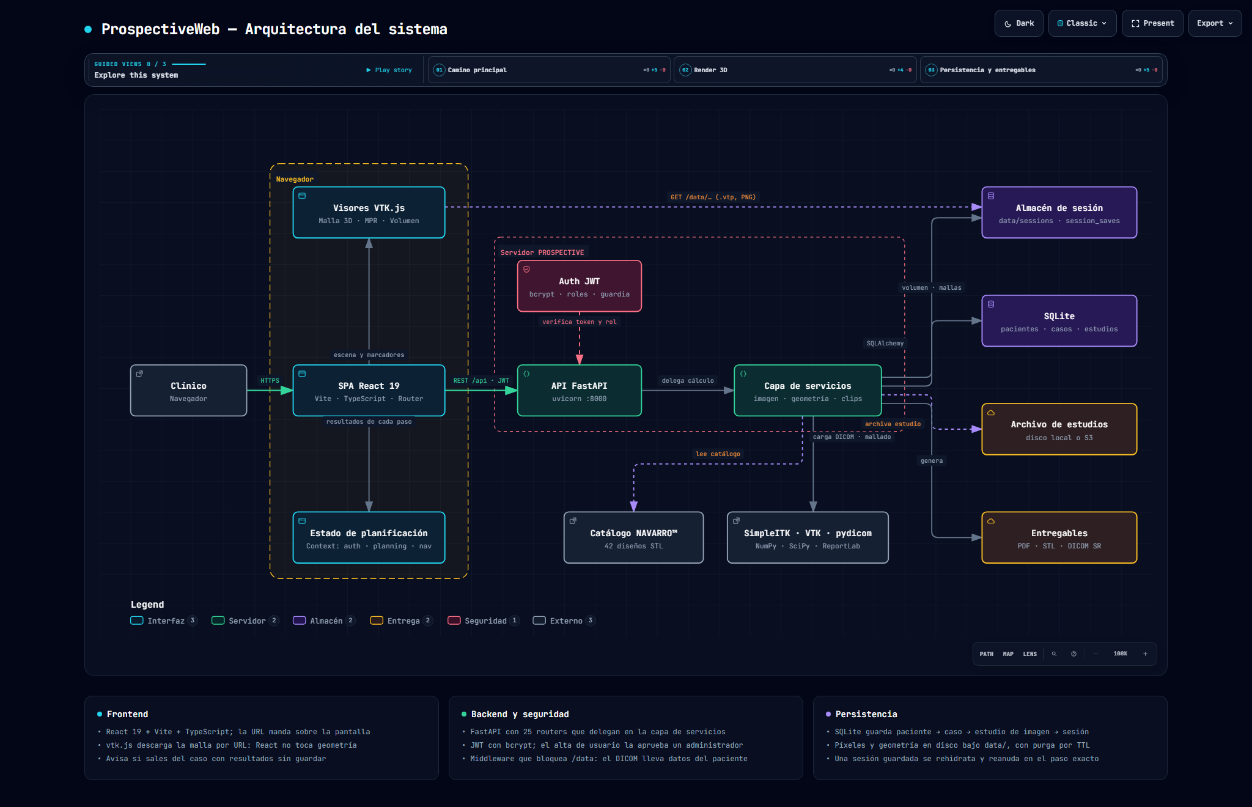
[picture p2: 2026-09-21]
docs/diagramas/prospectiveweb-arquitectura.visual-check.2048x1320.dark.png

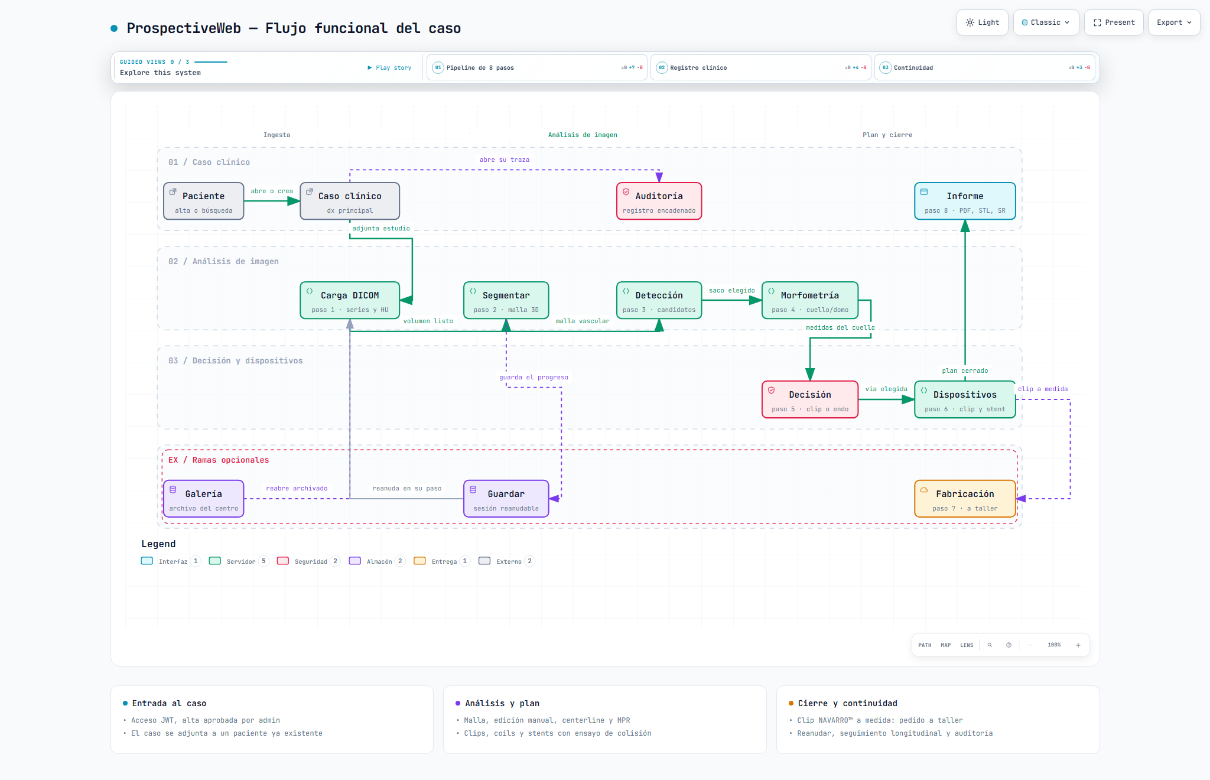
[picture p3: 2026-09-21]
docs/diagramas/prospectiveweb-flujo.visual-check.2048x1320.light.png

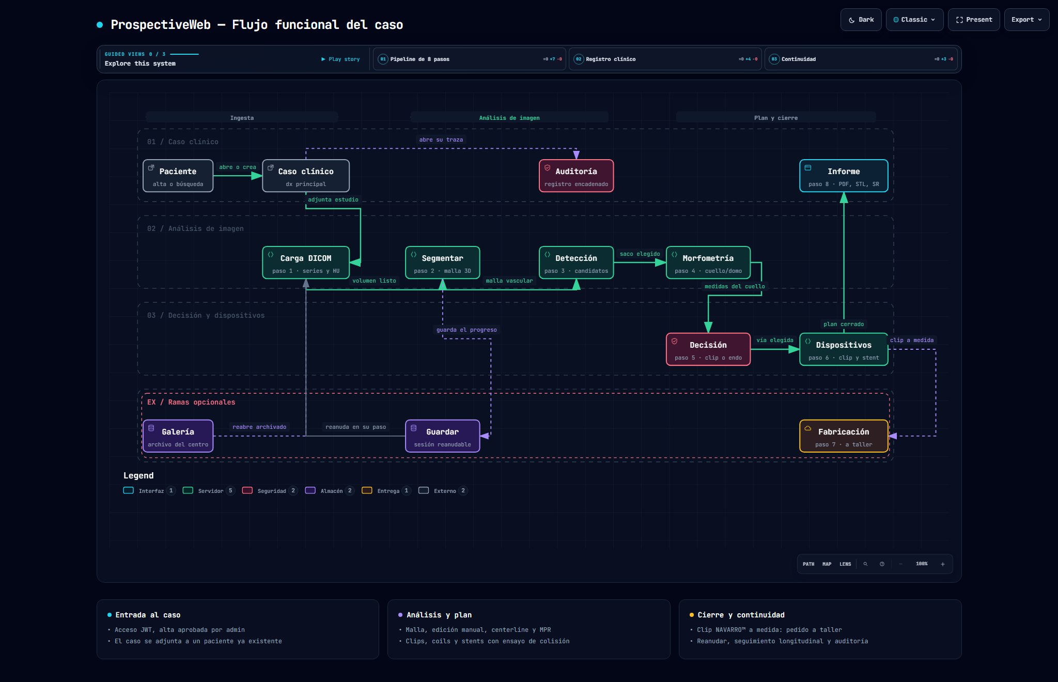
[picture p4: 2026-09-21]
docs/diagramas/prospectiveweb-flujo.visual-check.2048x1320.dark.png

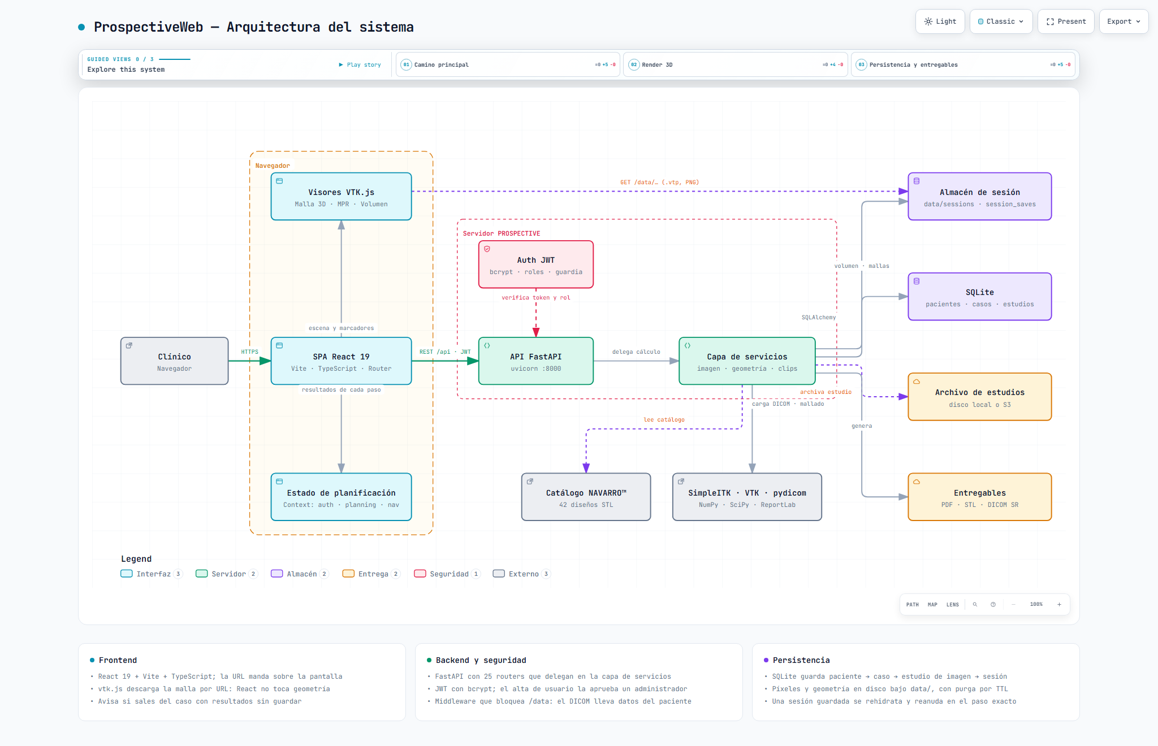
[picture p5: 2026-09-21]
docs/diagramas/prospectiveweb-arquitectura.visual-check.2048x1320.light.png

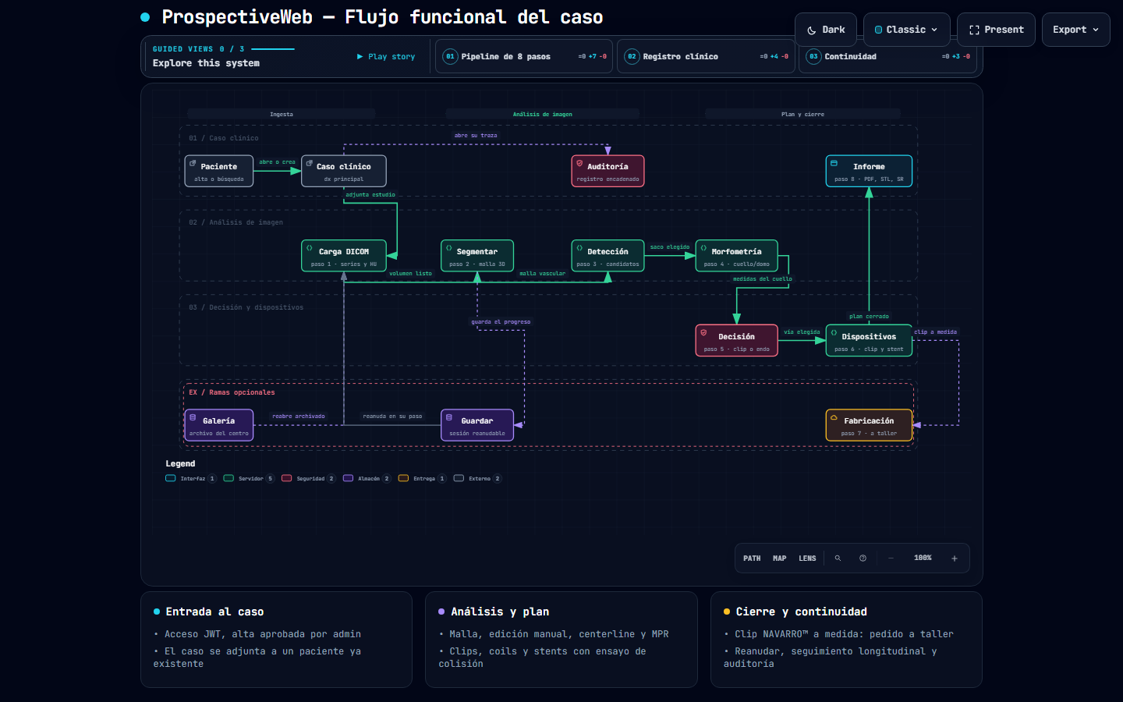
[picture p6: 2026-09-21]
docs/diagramas/prospectiveweb-flujo.visual-check.1440x900.dark.png

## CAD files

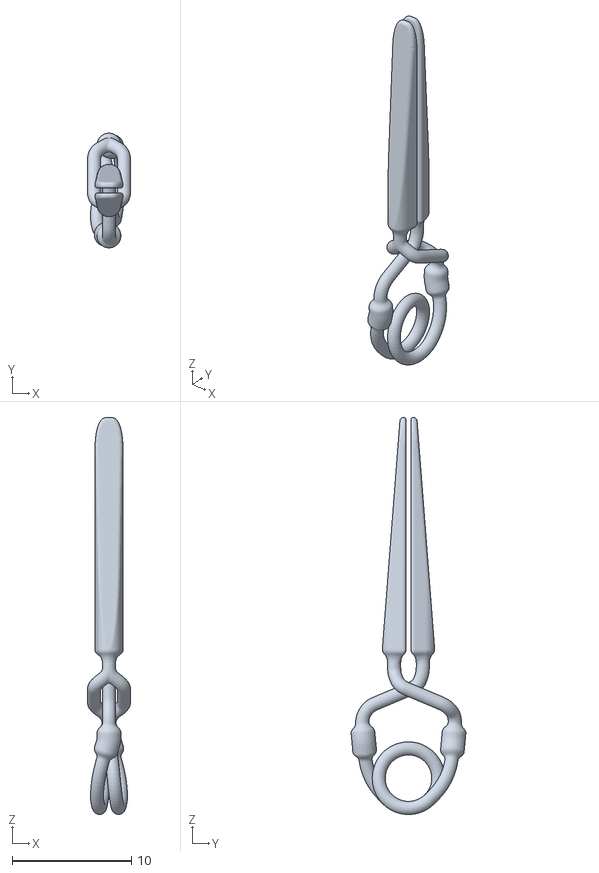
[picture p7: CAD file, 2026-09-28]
NAVARRO™ - Variantes/NAVARRO™ T1 — Straight/OBJ/NAVARRO™ T1 — Straight (19mm).stl
3.60 x 9.62 x 33.3

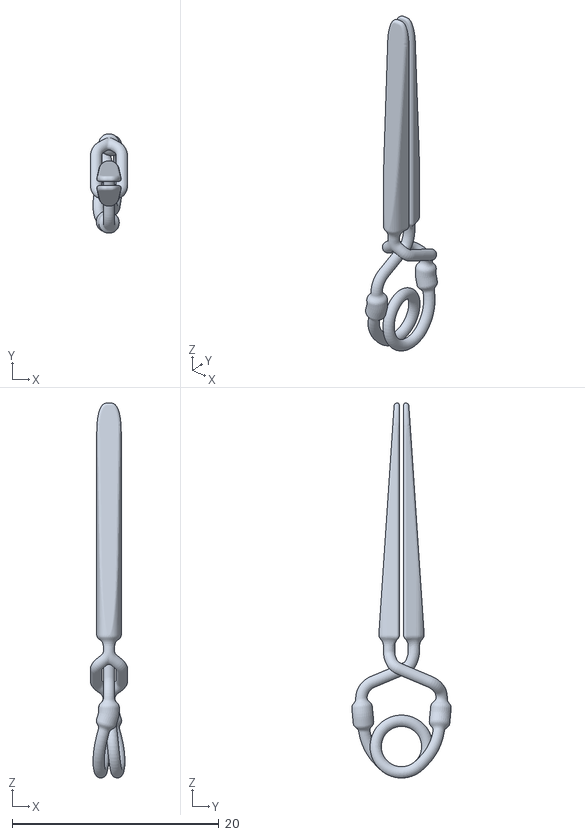
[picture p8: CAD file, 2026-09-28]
NAVARRO™ - Variantes/NAVARRO™ T1 — Straight/STL/NAVARRO™ T1 — Straight (22mm).stl
3.60 x 9.63 x 36.3

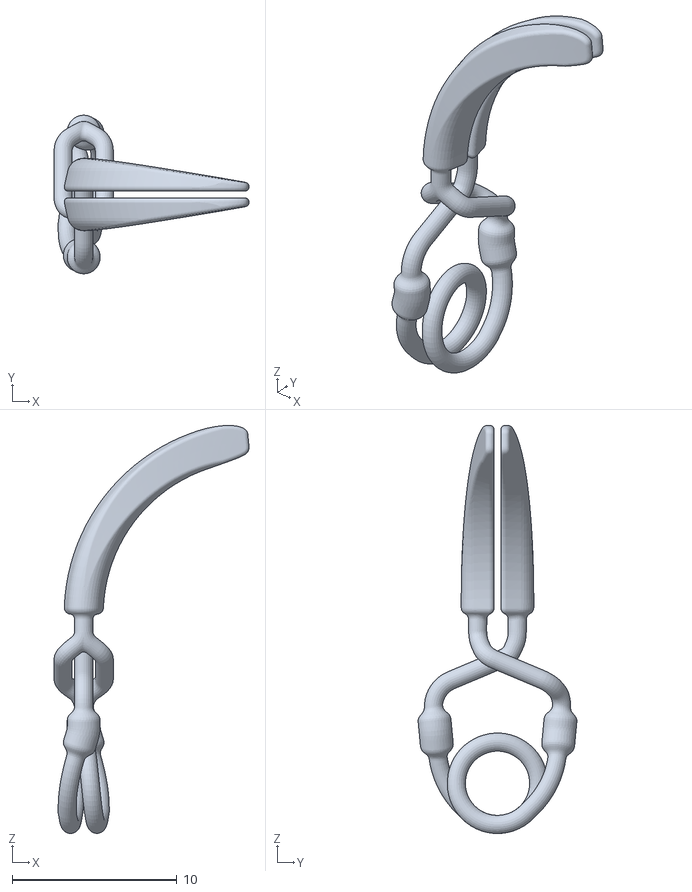
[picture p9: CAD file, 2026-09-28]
NAVARRO™ - Variantes/NAVARRO™ T2 — Curved/NAVARRO™ T2 — Curved(16mm).stl
11.8 x 9.63 x 24.7

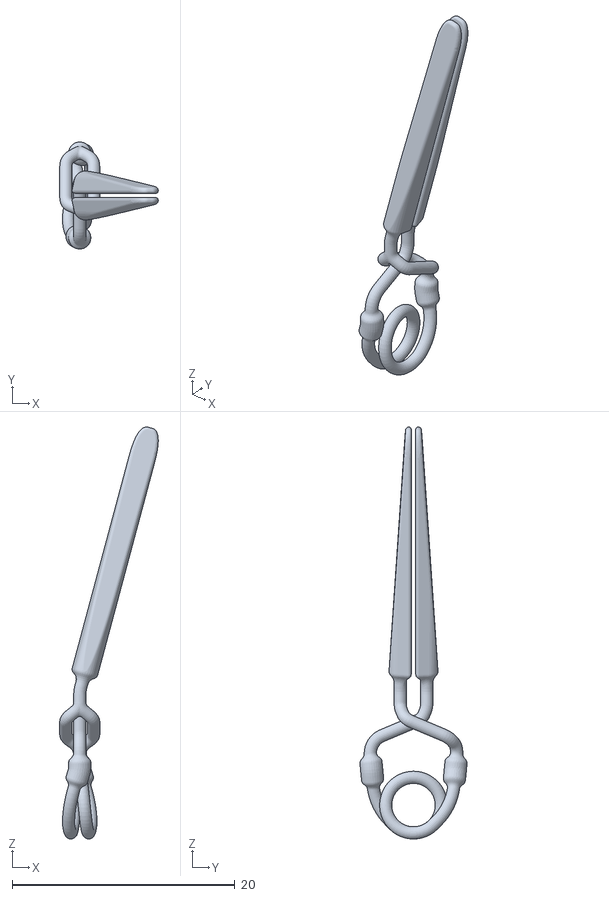
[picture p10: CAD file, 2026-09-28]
NAVARRO™ - Variantes/NAVARRO™ T3 — Angled/15°/STL/NAVARRO™ T3 — Angled 15° (22mm).stl
8.86 x 9.63 x 37.0

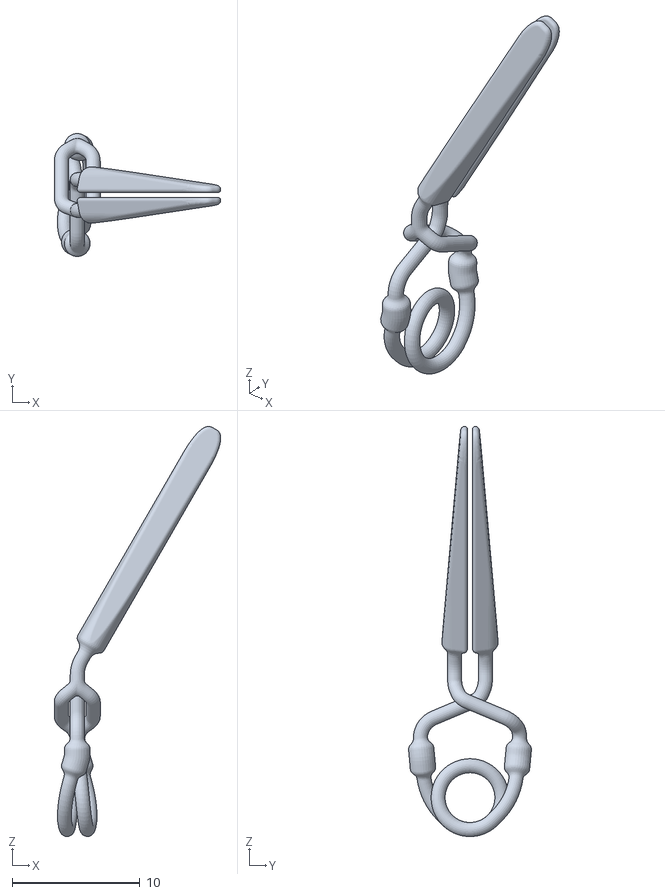
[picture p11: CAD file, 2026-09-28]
NAVARRO™ - Variantes/NAVARRO™ T3 — Angled/30°/STL/NAVARRO™ T3 — Angled 30° (19mm).stl
13.0 x 9.62 x 32.1

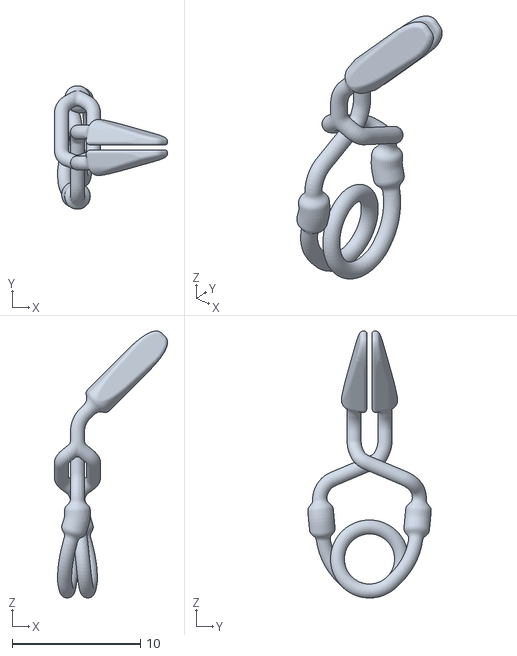
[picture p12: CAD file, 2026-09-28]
NAVARRO™ - Variantes/NAVARRO™ T3 — Angled/45°/STL/NAVARRO™ T3 — Angled 45° (7mm).stl
8.83 x 9.63 x 20.8

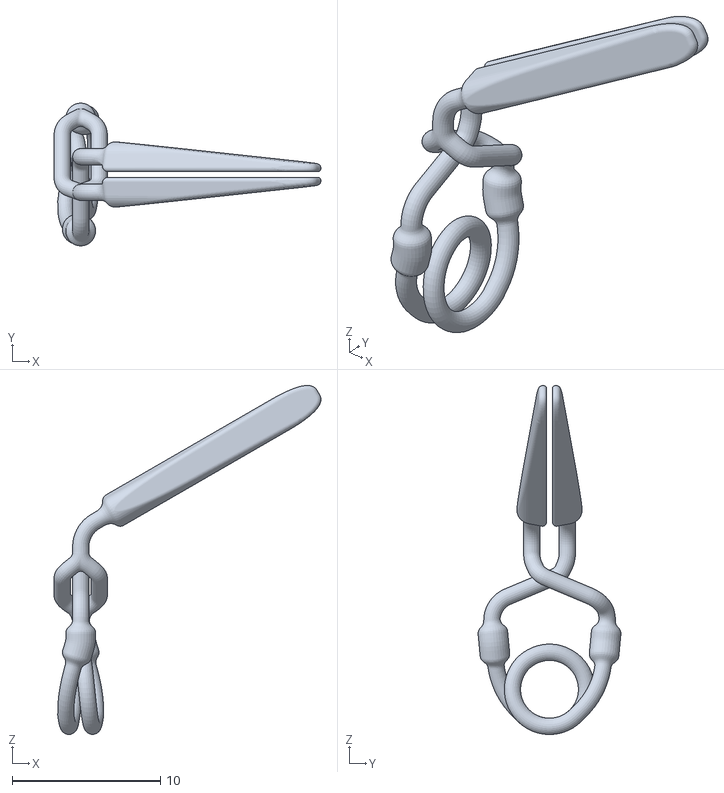
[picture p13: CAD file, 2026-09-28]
NAVARRO™ - Variantes/NAVARRO™ T3 — Angled/60°/STL/NAVARRO™ T3 — Angled 60° (16mm).stl
18.0 x 9.63 x 23.5

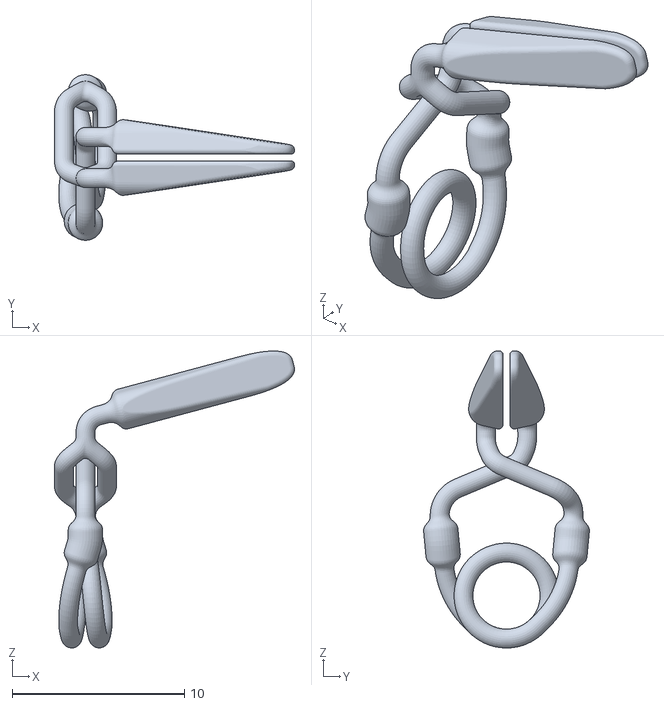
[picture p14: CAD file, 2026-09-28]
NAVARRO™ - Variantes/NAVARRO™ T3 — Angled/75°/STL/NAVARRO™ T3 — Angled 75° (10mm).stl
13.9 x 9.63 x 17.2

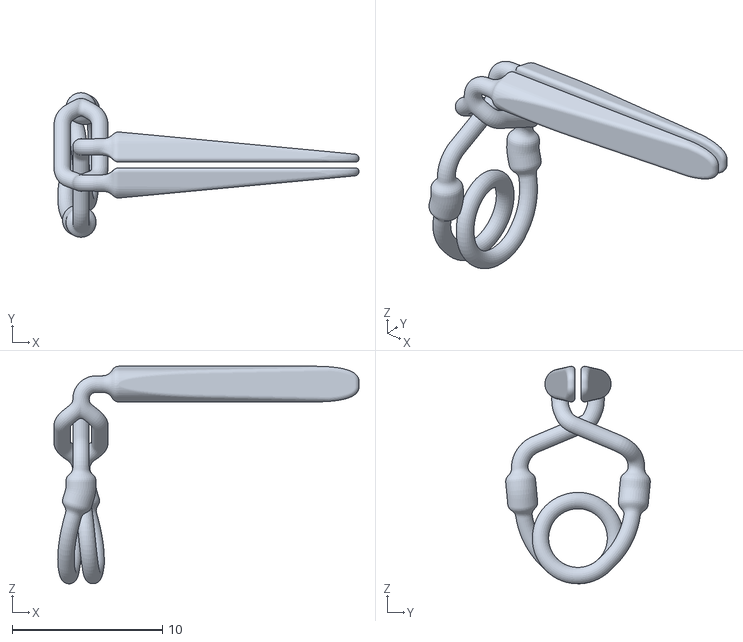
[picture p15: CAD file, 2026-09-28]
NAVARRO™ - Variantes/NAVARRO™ T3 — Angled/90°/STL/NAVARRO™ T3 — Angled 90° (16mm).stl
20.3 x 9.63 x 14.5

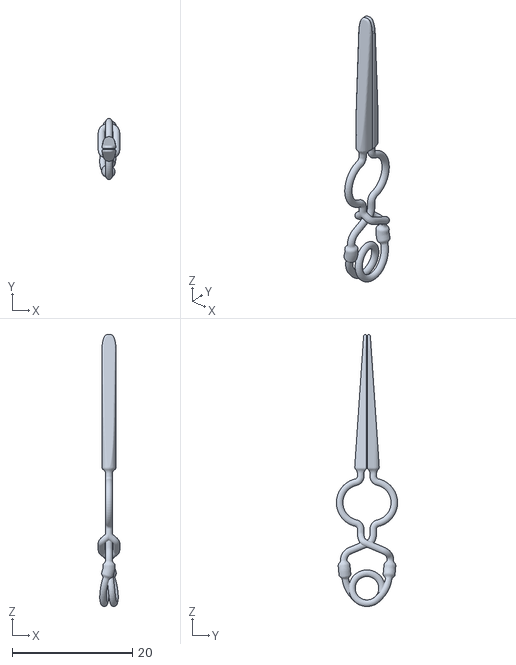
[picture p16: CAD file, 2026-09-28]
NAVARRO™ - Variantes/NAVARRO™ T4 — Fenestrated/NAVARRO™ T4 — Fenestrated (22x7mm).stl
3.60 x 10.2 x 45.3

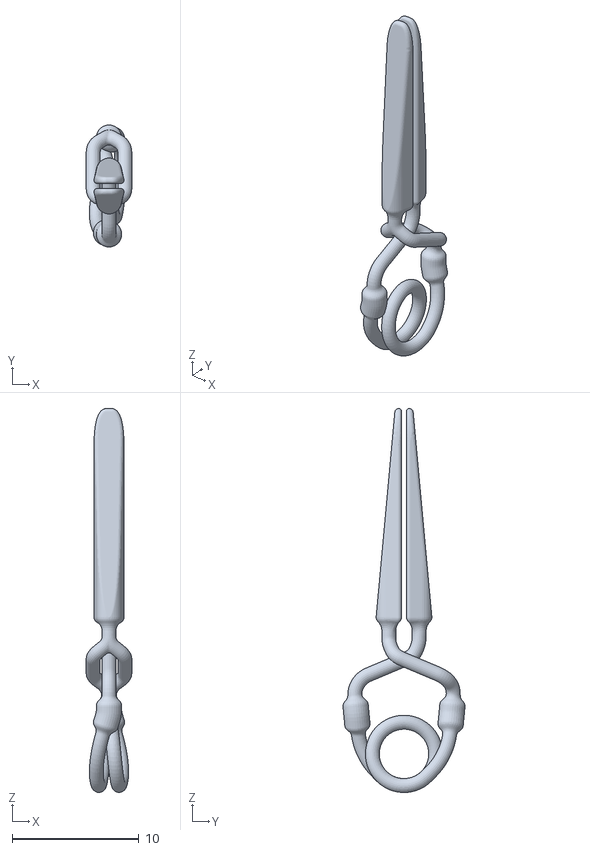
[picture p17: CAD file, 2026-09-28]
NAVARRO™ - Variantes/NAVARRO™ T1 — Straight/STL/NAVARRO™ T1 — Straight (16mm).stl
3.60 x 9.63 x 30.3

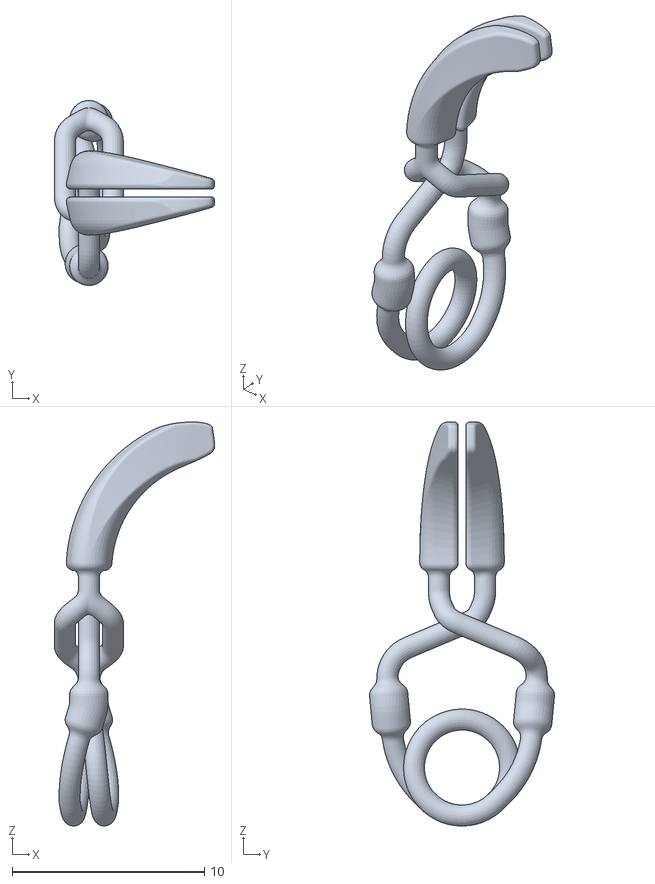
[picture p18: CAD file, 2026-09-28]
NAVARRO™ - Variantes/NAVARRO™ T2 — Curved/NAVARRO™ T2 — Curved(10mm).stl
8.35 x 9.63 x 21.0

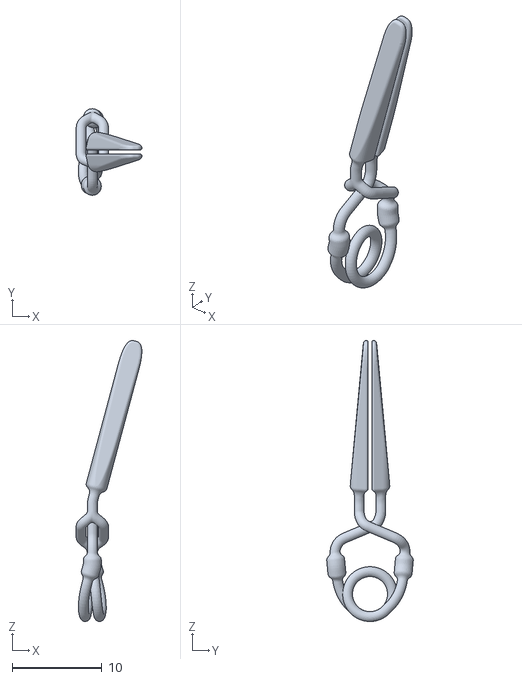
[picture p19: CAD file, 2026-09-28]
NAVARRO™ - Variantes/NAVARRO™ T3 — Angled/15°/STL/NAVARRO™ T3 — Angled 15° (16mm).stl
7.30 x 9.63 x 31.2

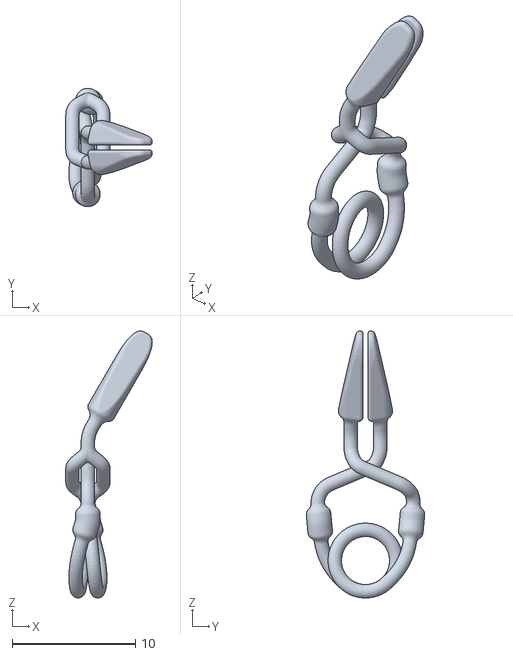
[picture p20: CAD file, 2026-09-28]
NAVARRO™ - Variantes/NAVARRO™ T3 — Angled/30°/STL/NAVARRO™ T3 — Angled 30° (7mm).stl
7.03 x 9.63 x 21.7

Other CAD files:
NAVARRO™ - Variantes/NAVARRO™ T3 — Angled/45°/STL/NAVARRO™ T3 — Angled 45° (19mm).stl
NAVARRO™ - Variantes/NAVARRO™ T3 — Angled/60°/STL/NAVARRO™ T3 — Angled 60° (19mm).stl
NAVARRO™ - Variantes/NAVARRO™ T3 — Angled/75°/STL/NAVARRO™ T3 — Angled 75° (13mm).stl
NAVARRO™ - Variantes/NAVARRO™ T3 — Angled/90°/STL/NAVARRO™ T3 — Angled 90° (13mm).stl
NAVARRO™ - Variantes/NAVARRO™ T1 — Straight/STL/NAVARRO™ T1 — Straight (10mm).stl
NAVARRO™ - Variantes/NAVARRO™ T1 — Straight/STL/NAVARRO™ T1 — Straight (13mm).stl
NAVARRO™ - Variantes/NAVARRO™ T1 — Straight/STL/NAVARRO™ T1 — Straight (7mm).stl
NAVARRO™ - Variantes/NAVARRO™ T2 — Curved/NAVARRO™ T2 — Curved(13mm).stl
NAVARRO™ - Variantes/NAVARRO™ T2 — Curved/NAVARRO™ T2 — Curved(19mm).stl
NAVARRO™ - Variantes/NAVARRO™ T2 — Curved/NAVARRO™ T2 — Curved(22mm).stl
NAVARRO™ - Variantes/NAVARRO™ T2 — Curved/NAVARRO™ T2 — Curved(7mm).stl
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

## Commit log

2026-09-02 Renderiza el clip en los dossiers y el plan 3D en el informe
    Los dossiers llevaban solo cotas: un taller podía fabricar una pieza
    dimensionalmente correcta y con la forma equivocada sin que nada lo
    detectara. Ahora ambas copias muestran tres vistas (superior, anterior y
    oblicua) del mismo sólido que va en el STL. No llevan datos de paciente:
    son fotos de un clip.
    El informe llevaba una sola imagen y venía del navegador —lo que el
    visor estuviera mostrando al pulsar el botón—, así que dos informes del
    mismo caso salían distintos y una sesión reanudada sin visor abierto no
    tenía imagen ninguna. Ahora el servidor dibuja cuatro vistas fijas
    (anterior, izquierda, superior y oblicua)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
2026-09-07 La mordaza a medida llega a las tres series, y la pestaña de clips se parte
    **La mordaza a medida.** La geometría siempre estuvo bien: recta, angulada
    y fenestrada salen con la longitud exacta pedida, medido sobre la malla.
    Lo que fallaba eran los dos caminos que la exponen.
    `suggest_custom_jaw` deducía del candidato ganador solo un ACODADO, nunca
    una forma, así que a un caso de bifurcación le ofrecía una mordaza recta a
    medida: la pieza equivocada con la medida correcta, la misma sustitución
    silenciosa que hacía el sustituto comercial. Y el endpoint que construye
    la vista previa no tenía parámetro de forma ni de ventana, así que un
    fenestrado a medida era inalcanzable. Ahora los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
2026-09-08 La portada anunciaba el catálogo retirado y un paso de menos
    Es la única página que un desconocido lee antes de decidir si esto le
    sirve, y la última que alguien actualizaba.
    Ofrecía «42 modelos» de Aesculap, Sugita y Codman meses después de que
    esos clips dejaran de servirse —un catálogo que la aplicación no devuelve
    y que este centro no puede conseguir— y prometía un flujo de «siete
    pasos» justo encima de las ocho fichas que ella misma dibuja desde
    `STEPS`.
    Las dos son el mismo error: una afirmación escrita a mano al lado del
    dato que la desmiente. El número de pasos ahora se deletrea desde la
    lista. La tarjeta de clips nombra la familia que sí se ofrece, con sus
    cuat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
2026-09-08 El vídeo del recorrido enseñaba siete pasos
    La última copia de la afirmación de siete pasos, y la única que no se
    arreglaba escribiendo: estaba quemada en los píxeles. Se renderizó el 21
    de julio, antes de que existiera Fabricación, con «PASO 0N / 07» en cada
    tarjeta. La fuente es una composición HyperFrames, así que había que
    editarla y volver a renderizar.
    Fabricación tiene ahora su tarjeta entre Dispositivos e Informe, y dice
    que es opcional, porque lo es: la mayoría de casos van con una talla
    dibujada y no pasan por ahí.
    La tarjeta de dispositivos arrastraba el mismo catálogo retirado que la
    portada —«42 clips» eran los de Yasargil, Sugita, Aesculap y Codman— y
    a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
2026-09-09 La recomendación dejaba de valer y seguía guardada
    `_clear_detection_state` protegía esto desde que se escribió, con el motivo
    al lado: «leaving them behind made the PDF recommend a treatment for an
    aneurysm the same PDF reported as unmeasured». Protegía la ruta de
    re-detectar. Las dos por las que esas medidas cambian en el uso normal, no.
    **Volver a medir el cuello a mano.** La morfometría automática de un
    casquete abierto da cuello 0. Se evalúa el tratamiento igualmente —el
    factor del cuello se salta— y después se marca el plano y el cuello pasa a
    3 mm. Medido, antes del arreglo:
    2) decisión: CLIPPING QUIRÚRGICO · cobertura 59 % <- con cuello 0.0
    3) cuello re-medi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
2026-09-10 El veredicto se partía letra a letra, y la procedencia tapaba los factores
    **El titular.** «Recomendación: TRATAMIENTO ENDOVASCULAR» salía como
    «TRAT / AMIE / NTO / ENDO / VASC / ULAR» en el panel de 265 px.
    Compartía una fila flex con insignias que no encogen, y llevaba
    `overflow-wrap: anywhere`. Al añadir la insignia de cobertura el texto se
    quedó con unos sesenta píxeles, y `anywhere` hace exactamente lo que dice:
    parte a mitad de palabra antes que desbordar. Ahora el titular manda en su
    línea y las insignias envuelven en la suya, con envoltura normal por
    palabras — sin ninguna regla que pueda romper una palabra.
    **La procedencia.** Cada factor arrastraba su fuente complet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
2026-09-10 El borde izquierdo de los factores quedaba dentado
    La insignia de dirección se ajustaba a su contenido, así que «ENDO +25» y
    «CLIP ·» medían distinto y el texto de cada fila arrancaba en una columna
    diferente. Con seis factores el borde izquierdo quedaba en zigzag.
    Rejilla en vez de flex: una primera columna de ancho fijo alinea las filas
    por construcción, en lugar de depender de cuántos caracteres tenga la
    puntuación. El texto se centra dentro de la insignia y ya no la rompe.
    De paso, el chip «no puntúa» se partía en dos líneas —«no / puntúa»—
    cuando el nombre del factor era largo, que es justo cuando aparece. Con
    `white-space: nowrap` se queda entero o baja de lín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
2026-09-21 feat: add landing page styles and components
    - Introduced new landing.css for the public landing page with a dark theme and glassmorphism design.
    - Updated index.css to import landing.css.
    - Added font definitions for Space Grotesk and Plus Jakarta Sans to fonts.css for landing page typography.
    - Enhanced test setup to handle canvas context for WebGL in tests, preventing errors during rendering.
    - Updated tsconfig to include new landing components and scenes for the landing page.
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2026-09-22 El corte por plano era invisible, que es lo que lo hacía inútil
    El usuario dice que cortar por ejes es poco intuitivo «porque no hay de dónde
    guiarse». Tiene razón, y el problema no era la forma: era que mueves un número
    de −0 a 87 sin ver nada hasta pulsar Cortar. Había cambiado «acertar un centro
    a ojo» por «acertar una altura a ciegas», que es el mismo defecto mudado de
    sitio.
    Propuso una caja o esfera que se mueva por la malla. No lo hago, y el motivo
    es que para quitar la chapa de abajo una caja son nueve grados de libertad
    manipulados con un ratón sobre una pantalla plana — más tanteo, no menos. Un
    plano es un grado de libertad, que es justo lo que hace falta. Lo que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
2026-09-22 El resalte tapaba justo donde hay que pinchar, y dos cosas no se podían deshacer
    El usuario marca el cuello y el ápice pinchando la superficie, y el resalte
    opaco del candidato tapa el sitio. En Morfometría —y con cualquier modo de
    marcado activo— baja al 35 %: sigue diciendo dónde está y deja ver el relieve.
    Y recordó que todo debe poder revertirse. Lo tomé como regla y audité lo de
    esta sesión. Salieron dos agujeros, los dos míos:
    1. La previa del corte por plano SE ARMABA SOLA. El efecto la publicaba en
    cuanto llegaban los límites, así que entrar en Segmentación recortaba la
    vista sin que nadie lo pidiera — y en una malla cuyos límites no incluyan
    el cero, m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
2026-09-22 Arregla el literal roto que se coló en el commit anterior
    El heredoc con el que escribí la descripción de POST /api/patients/case
    convirtió los \n del texto en saltos de línea reales y dejó el fichero con
    SyntaxError: unterminated string literal. El error salió mezclado con los
    avisos de CRLF de git add y lo pasé por alto, así que 0f96d11 quedó con el
    backend sin arrancar.
    - routers/patients.py: la descripción vuelve a ser un literal válido.
    - openapi.json: regenerado (98 rutas), con el endpoint marcado SUPERSEDED.
    Verificado importando routers.patients y main en su propio comando, no
    encadenado a git, y con la suite completa: 915 pasan.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
2026-09-22 Tres cifras de coils y stents que parecían medidas y no lo eran
    La vía endovascular tenía catálogos buenos conectados a cálculos inventados.
    Ninguna de las tres cifras se reajusta: se retiran, porque el problema no era
    el valor sino que ocupaban el sitio de una medición.
    1. La oclusión estimada de los coils salía de `1 - exp(-packing/0.10)`, una
    curva ajustada a ojo y sin fuente, pintada con un decimal. La escala de
    Raymond-Roy tiene tres clases ordinales y se valora sobre la angiografía
    posterior; no hay curva publicada que la derive del empaquetamiento. Se
    retira `estimated_occlusion_pct` y en su sitio va `durability`, que dice lo
    que la densidad medida sí permite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
2026-09-24 Segmentar volvía a la vista del DICOM: la malla se ponía y se borraba sola
    Encontrado por el usuario probando en vivo: «al darle Segmentar no se muestra
    la malla, se carga otra vez la vista del dicom». En el log del backend está la
    huella exacta: `POST /api/segment` responde 200 y detrás NO hay ningún GET de
    `vessel_tree.vtp` — el frontend recibía la malla y no llegaba a pedirla.
    La causa la metí yo en 44a39a9. Para invalidar lo medido sobre la malla
    anterior llamé a `resetDownstream()`, que está pensado para «se ha subido otra
    serie» y limpia TODO lo que cuelga del DICOM, la propia segmentación incluida
    (`_setSegmentation(null)`). Como lo llamé DESPUÉS de `setSegmentation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
2026-09-25 El motor de tratamiento deja de enseñar puntajes
    Pedido por dirección: solo la recomendación final —clip o endovascular— y la
    justificación, sin rastro de puntuación.
    POR QUÉ ES LO CORRECTO
    ----------------------
    «CLIP 72 % · ENDO 28 %» era el cociente de dos sumas con pesos elegidos a mano,
    normalizado a 100. No es una probabilidad, ni la proporción de pacientes a los
    que les fue mejor, ni un intervalo de confianza. Ya se había intentado
    arreglarlo poniendo los puntos crudos en vez del porcentaje, con una línea
    explicando lo que eran; no bastaba, porque un número en pantalla se lee como
    una medida aunque debajo diga que no lo es.
    QUÉ SALE Y QUÉ SE QUEDA
    ----------------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
2026-09-25 Cuatro fallos más del navegador: el saco nunca se deformaba
    El punto 7 no llegaba a la pantalla. `clip_animation` calcula los
    fotogramas del saco constreñido dentro de un `try` que se traga el fallo
    —«un dibujo no hunde el ensayo»—, y le faltaba el `from services import
    devices`. En producción el log decía «Sac constriction frames skipped:
    name 'devices' is not defined» y el ensayo salía sin deformación alguna.
    Ninguna prueba lo vio porque la sesión de prueba no escribía
    `aneurysm_sac.vtp`, así que el bloque entero se saltaba por el `if`.
    Ahora hay tres pruebas que sí entran: cuatro ficheros escritos, la caja
    del saco encogiendo en cada fotograma sin que ningún lado crezca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
2026-09-25 Cambiar de serie, preprocesar o revertir recarga el volumen del visor
    La meta solo se pedía al cambiar de sesión, así que las celdas 2D, el MIP
    y el oblicuo seguían pintando el volumen anterior. El store lleva ahora un
    volumeVersion que se sube tras setActiveSeries, preprocess y
    revertPreprocess; useVolumeMeta (en su propio módulo) depende de él y el
    cache_key nuevo recarga el volumen del navegador.
    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
2026-09-25 Las vistas AX/COR/SAG del 3D se definen en LPS y pasan por la orientación
    Suponían +z superior en coordenadas del volumen: en el Case 3 (k→A) «AX»
    enseñaba una vista coronal mientras la cinta de rumbo decía otra cosa.
    standardViewInVolume lleva cada vista (desde dónde y qué queda arriba) de
    LPS a ejes del volumen con la dirección efectiva; con la identidad las
    vistas no cambian.
    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
2026-09-25 standardViewInVolume devuelve { direction, viewUp } y se prueba contra su definición
    La vista estándar da ahora la dirección de proyección y el «arriba» en
    coordenadas del volumen, como pide la resolución del addendum. Los tests
    comprueban que con la identidad salen los vectores de siempre y que, con la
    dirección del Case 3, cada vista mira y queda orientada en LPS como dice su
    definición, con la cinta de rumbo a EL 90° para AX, AZ 0° para COR y AZ 90°
    para SAG.
    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
2026-09-26 El orden documenta que los límites de la malla solo son el borde del volumen donde salen vasos
    Solo comentarios en aneurysm_consensus: la salvedad de region_on_border y
    order_hits (una cúpula real en el extremo del árbol se degradaría, nunca se
    quitaría) y el arreglo exacto pendiente (pasar la extensión del volumen a
    _detect_hits).
    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
2026-09-26 Segmentar tras preprocesar se prueba de extremo a extremo y ya no carga el DICOM que no va a usar
    La revisión de Task 12 pidió que el arreglo del preprocesado quedara fijado
    por una prueba del recorrido completo, no solo del helper: quitar la llamada
    en _run_segmentation_sync dejaba la suite en verde.
    - test_segment_tubular.py::TestSegmentarTrasPreprocesar: serie de tubo,
    remuestreo a 2 mm, POST /api/segment, y dicom.volume_* dice 40×24×24;
    tras «Restaurar», 80×48×48. Quitar el enganche hace fallar dos pruebas.
    - Con la sesión preprocesada ya no se lee el DICOM: _preprocessed_source
    arma el resultado desde la caché (forma, espaciado, dirección y modalidad
    de su meta; vent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
2026-09-28 Los módulos de vtk.js se empaquetan al arrancar, no a mitad de sesión
    «Failed to fetch dynamically imported module: …/src/vtk/SliceView.tsx»,
    nada más abrir el visor por primera vez tras el merge. El fichero estaba
    y se servía con 200: el mensaje despista porque parece que falta.
    Los visores se cargan con `import()` diferido, así que Vite no ve sus
    dependencias al arrancar. Las descubría la primera vez que alguien abría
    uno —ImageMapper, ImageSlice, GenericRenderWindow, AnnotatedCubeActor,
    los que traen SliceView, MipView y el maniquí—, las pre-empaquetaba en
    caliente y forzaba una recarga; los `import()` en vuelo en ese momento se
    caían. El log del servidor lo dice a su ma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
2026-09-28 El botón de captura sale del HUD y se pone donde se busca
    El usuario probó la app y no encontró cuándo se podían tomar capturas.
    Estaban disponibles en todos los pasos desde el primer día; el problema
    era el botón.
    Vivía en la capa HUD del visor, arriba a la izquierda: 11 px de mono,
    sin fondo ni borde, en `--hud-dim` al 55 % — es decir, exactamente el
    mismo tratamiento que los rótulos de instrumento que tiene debajo
    («ANÁLISIS MORFOMÉTRICO», «cand-001 · Ø 5.6 mm»). Leído en pantalla
    parecía el título del panel, no algo que pulsar. El HUD es lenguaje de
    lectura; meter ahí la única acción que produce un archivo del caso fue
    un error mío.
    Ahora es un botón de verda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
2026-09-29 La tijera corta donde se marca, también en vasos en lazo
    - Solo se puede pinchar la mitad visible del vaso: el centro se recupera
    ajustando una circunferencia al arco, y la bola se dimensiona con la
    sección real de la malla en ese plano. En una malla de paciente, 60 de
    60 anillos simulados cortan (antes 40).
    - Si el vaso está en un lazo (anastomosis, vasos fundidos), el corte no
    desprende nada: ya no es un error, se enseña el tajo y se puede cortar.
    - El tajo pasa de 3 mm a 1 mm y se pinta en rojo con la pieza: antes el
    rojo empezaba por debajo del anillo aunque la franja también se borraba.
    - El contador del visor cuenta los puntos de la tijera, no los del cuello.
    - La tarjet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
2026-10-01 Ctrl+rueda arriba acerca el MIP, como en los cortes
    El manipulador de zoom de vtk acercaba al girar hacia abajo y en 36.2.1
    su onScroll no atiende a flipDirection. El MIP resuelve Ctrl+rueda en su
    propio oyente con el paso 1,1 de SliceView; wheelAction lleva el factor
    y una prueba fija el sentido.
    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
2026-10-01 Cierre del mapa de calor del clip: lista manual y README
    Comprobación: tsc -b limpio; vitest 473/473; build OK; pytest 36 fallos,
    todos de la línea base (ninguno nuevo; el flaky de corredor pasó).
    POST /api/clips/field sobre Case 3 (malla tubular): 53–82 ms.
    Lista manual (Case 3, cuello 1.1 mm, saco cerrado 11.4 mm³):
    1. OK: T1 Recto 10 mm colocado pinta el saco; leyenda abajo a la derecha con cubierto 100 %, residual 0 %, no alcanzado 0 %, presión 1.7 g/mm² óptima (1.1–1.7) y «VEREDICTO FAIL · ESTIMACIÓN GEOMÉTRICA».
    2. OK con matiz: 2–5 mm no cambian nada en este cuello; Z −6 mm da residual magenta 32 % y Z −8 mm 82 %; el veredicto ya era FAIL antes de mover (hoja ×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
2026-10-01 Cierre de la coherencia del visor (D1): lista manual y README
    Comprobación completa: tsc, vitest 498/498 en 65 archivos (495 + 3 de
    presetOptions), build OK; backend 36 fallos, los preexistentes.
    Lista manual con Case 3 (Chrome, 1280×720, DERECHA):
    1. PRINCIPAL ▸ AX / ▸ VOL cambian la principal; el selector refleja el
    doble clic y el «⤢». Sí.
    2. «⤢» en las cuatro secundarias, nunca en la principal. Sí.
    3. Rótulos con su color (axial #4cc9f0, coronal #80ed99, sagital #f4a261) y
    líneas de referencia con data-plane y el color de los otros dos planos. Sí.
    4. Tres rectángulos y el punto en el 3D; la rueda en el axial (192→132) mueve
    el cian; coincide con la traza d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
2026-10-02 Cierre del volumen unificado (D2): lista manual y README
    Comprobación: tsc limpio; vitest 542/542 en 69 archivos; build correcto;
    pytest backend 36 fallos preexistentes (línea base 36-37), ninguno del raw.
    Lista manual con Case 3:
    1. Oblicuo: AZIMUT/ELEVACIÓN y arrastre derecho orientan; la rueda se
    detiene en la caja (+127,5 mm); CENTRAR y AJUSTAR: sí.
    2. VOLUMEN LIBRE muestra el mismo plano; la rueda se sincroniza en los dos
    sentidos: sí.
    3. Cara en gris con la ventana de los cortes; CARA ○ la quita; los vasos
    de delante la tapan: sí.
    4. LÁMINA en LIBRE recorta ±slab; DESDE EL FINAL invierte: sí.
    5. EJE devuelve el recorte por eje; CENTRAR encuadra como en D1; sin
    r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
2026-10-02 «Adjuntar a un caso» y arreglos de la revisión en el navegador
    Adjuntar a un caso: una sesión puede empezar sin paciente y ligarse
    después en una sola operación (botón en la barra superior mientras no hay
    estudio archivado).
    - Paciente existente o nuevo, y caso existente o nuevo con solo el motivo.
    - Archiva el DICOM ya subido como estudio del caso, sin volver a subirlo,
    y liga la sesión.
    - Pasa al estudio la confirmación de lesión hecha antes.
    - Queda en auditoría (SESSION_ATTACHED).
    - Si algo falla, no deja paciente ni caso a medias.
    - La cabecera DICOM solo propone los datos: el profesional los rellena con
    un botón y los confirma. Si ese nº de historia ya existe, se elige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
2026-10-03 Cierre de la navegación y orientación (E1): lista manual y README
    Lista manual con Case 3 (Chrome, celda VOLUMEN principal 704x912):
    1. PASS VOLUMEN: deriva 0 px del punto tras dos giros (AZ -180 a -9 a -52, EL -27) en MIP, otros dos tras CENTRAR, uno en COMPUESTO y uno en LIBRE; Av Pág x2 152->132 sin mover la cámara. CENTRAR: acumulado 83x90 %, lámina ±10 mm 90 % de ancho, libre 90 % centrado a 0 px; centra lo visible, no el punto.
    2. PASS CUATRO: cuatro celdas de 492x456; Alt+4 deja AX, 3D, COR, SAG en orden de lectura y aparta VOLUMEN; «VOL» y «⤢» lo traen; Alt+2 vuelve a DERECHA (con el foco dentro del visor).
    3. PASS Cortes 3D: tres cortes no seleccionables cruzados en (54.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
2026-10-03 Revisión final de E1: el cine se para al ocultar su celda o con Escape desde cualquier sitio
    Importantes:
    - La distribución que oculta la celda que reproduce para el cine y suelta
    el foco de una celda oculta (cineShouldStop, puro y probado).
    - Escape llega al visor por viewer:shortcut esté donde esté el foco; sigue
    cancelando el modo de marcado.
    - «⤢» devuelve el foco a la celda subida (o a la rejilla en la 3D).
    - En Cortes 3D con MALLA ○ la malla vuelve a verse al 35 % mientras hay un
    modo de marcado: el picker no mira la opacidad.
    Menores:
    - VOLUMEN apila la barra del cine y la fila de preajustes en una columna;
    el recuadro de orientación sube en píxeles, no en fracci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
2026-10-04 Archivo de estudios: comparar rutas ya resueltas (nombre corto de Windows)
    Segundo hallazgo de la integración continua. LocalBackend.list_prefix
    comparaba los ficheros ya resueltos con la raíz SIN resolver. En una
    máquina donde la carpeta llega con el nombre corto de Windows (RUNNER~1) y
    resolve() la devuelve con el largo, relative_to fallaba y archivar un
    estudio daba error. Pasaría igual con un enlace o una ruta relativa en
    STUDY_FILES_ROOT.
    De paso, la guarda contra «..» comparaba por prefijo de texto:
    «study_files_otro» empieza igual que «study_files» y la pasaba. Ahora
    compara por componentes.
    Claude-Session: https://c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
2026-10-04 Test del enlace duro: solo se exige si archivo y sesión comparten disco
    Un enlace duro no cruza volúmenes; ahí el backend copia, que es lo
    correcto. En la máquina de integración continua el temporal está en C: y
    el repositorio en D:.
    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
2026-10-04 Revisión en el navegador: cuatro arreglos de lo visto en pantalla
    - Aposición: los extremos proximal y distal van en dos filas; en una sola
    la cifra se partía carácter a carácter.
    - Las seis pestañas de Morfometría no cabían y ensanchaban el panel entero
    (barra horizontal y contenido cortado): ahora se parten en dos filas.
    - ELAPSS rellena la edad con la fecha de nacimiento, como UIATS; salía
    siempre 60.
    - El login ya no enseña «Demo: admin / admin123» (la contraseña inicial
    hay que cambiarla al entrar) ni el recuento viejo de endpoints.
    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
2026-10-08 Cierre de las anotaciones persistentes (E2): lista manual y README
    1. PASS regla en axial: R1 44,2 mm en panel y corte, visible en 3D, fuera en AX 153-155.
    2. PASS regla en 3D: R2 13,8 mm, plane null, se dibuja en AX 158 y AX 165 (sus extremos).
    3. PASS A1 90° en COR 53; G1 762 mm² (cerrada por el primer punto) y G2 214 mm² (Intro) en SAG 263; M1 con nota en 3D.
    4. PASS Retroceso 3→2 puntos, Esc vacía y desarma, Supr 6→5, R/A/G/T arman y desarman, nada con foco en la nota.
    5. PASS guardar y reanudar: las 6 vuelven con sus nombres; re-segmentar deja el panel vacío y PUT [].
    6. PASS capturas con R1, G1, G2 y A1 pintadas; tabla del PDF con los valores del panel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
2026-10-08 Anotaciones: no pisar el disco tras una lectura fallida, no borrarlas al segmentar por primera vez, topes del servidor y foco en la nota
    - annotationsLoadState: con una lectura fallida al reanudar el guardado
    automático no escribe y el panel dice «no se pudieron cargar».
    - resetDownstream ya no vacía las anotaciones; clearAnnotations() solo al
    resegmentar una malla existente, subir otro DICOM, cambiar de serie y
    preprocesar. La subida las vacía después de setSession (sin PUT [] a la
    sesión anterior).
    - maxLength/slice de 40 y 500, tope de 200 en el visor y en el panel.
    - flush() devuelve boolean: «Guardar progreso» avisa y no marca guardado.
    - Un marcador nuevo abre «Anotac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
2026-10-09 Cámara 3D: segundo clic en AX · COR · SAG mira la cara opuesta; mirar a lo largo de una dirección
    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
2026-10-11 Serie F: plan de ejecución de la auditoría funcional (F1)
    Diez tareas: esqueleto del informe y script de comprobación, una tarea por
    zona (entrada, gestión en dos, espacio de trabajo, pasos 1–3, 4–5, 6–8,
    usuario no administrador) y la consolidación con el recorrido del
    especialista, las eliminaciones propuestas y los arreglos F1.
    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
2026-10-11 Auditoría F1: pacientes, correcciones de la revisión
    Sexo, tratamiento propuesto, antecedentes y error de recarga de casos pasan
    a F1; el panel de contadores se corrige en vez de eliminarse.
    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
